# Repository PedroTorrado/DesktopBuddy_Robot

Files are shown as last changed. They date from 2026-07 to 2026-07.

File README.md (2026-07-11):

# Project Mimir

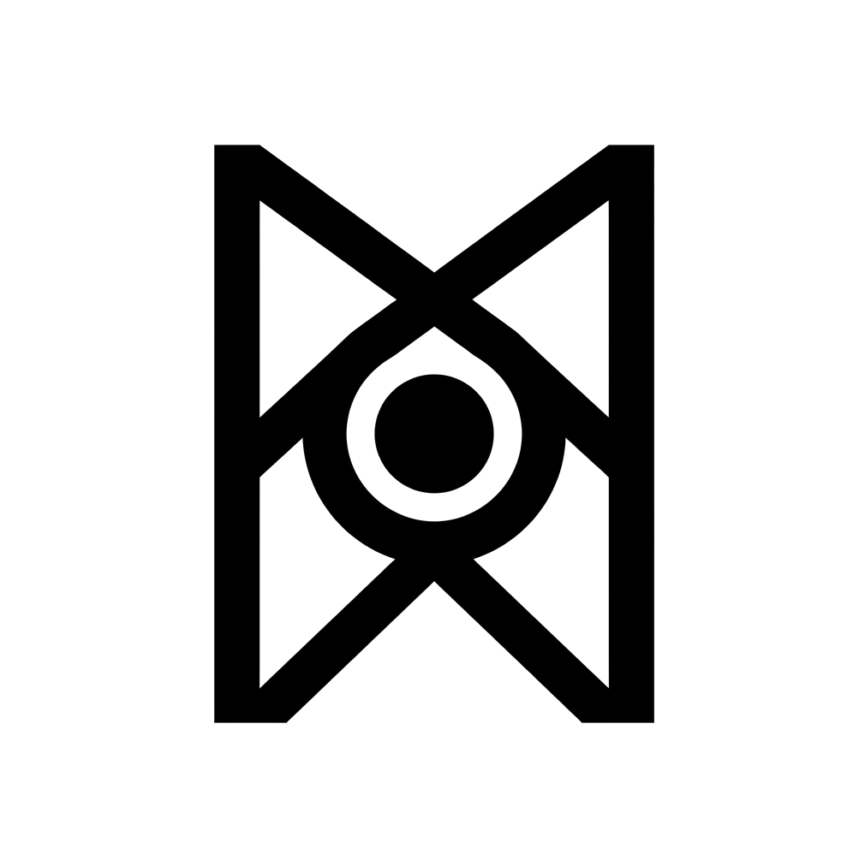
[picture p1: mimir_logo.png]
Project Mimir Logo


An autonomous, reactive, and expressive robotic companion built with an ESP32-CAM and STM32 Nucleo.

## ᛗ Runic Symbolism
The project logo features the Norse rune **Mannaz (ᛗ)** representing humanity and the mind, combined with a central camera lens. This symbolizes the camera's core objective: searching for, tracking, and identifying human faces. The name *Mimir* refers to the wise Norse sentinel head whose well guards Odin's sacrificed eye.

## Features
*   **Neural Network Face Tracking**: Uses the ESP32-CAM to detect faces and dynamically tracks them using a Proportional-Integral (PI) motor loop.
*   **SD Card Wi-Fi Loader & OLED Selector Menu**: Reads custom networks on-the-fly from `/wifi.txt` on a MicroSD card. Allows interactively scanning and joining networks via the Nucleo OLED screen and button long-press.
*   **Dynamic Telemetry Refresh Rate**: Switch between **Eco (5s)** and **Turbo (1s)** refresh modes directly from the web dashboard to control cloud costs or increase responsiveness.
*   **Startup Link Verification**: Automatic serial handshake (`PING/PONG`) on boot to visually confirm TX/RX wire integrity.
*   **Emotion Engine**: A state machine that gives the robot a personality (Happy, Searching, Dizzy, Angry) based on sensor inputs.
*   **Sensory Suite**: Monitors room air quality (SGP30) and avoids collisions with ultrasonic sonar (HC-SR04).
*   **Cloud Telemetry**: Streams data to AWS IoT Core over MQTT.

## Expressive Personalities
Project Mimir uses its SSD1306 OLED display to express its emotions dynamically based on sensor inputs:

### HAPPY (Tracking)
```text
                   ▄█▄                     ▄█▄
                 ▄██▀██▄                 ▄██▀██▄
               ▄██▀   ▀██              ▄██▀   ▀██
               █▀       ▀              █▀       ▀

                      █▄                 ▄
                      ▀██▄             ▄██
                        ▀██▄         ▄██▀
                          ▀██▄     ▄██▀
                            ▀██▄ ▄██▀
                              ▀███▀
                                ▀
```

### ANGRY (Obstacle Alert)
```text
                        ▄█              █▄
                      ▄█▀               ▀██▄
                    ▄█▀                   ▀██▄
                  ▄█▀                       ▀██▄
                ▄█▀                           ▀██▄
               ██████████              ███████████
               ██████████              ██████████
               ██████████              ██████████
               ██████████              ██████████
               ██████████              ██████████

                                   ██████████
```

### DIZZY (Jerk/Bump)
```text
               ▀▄        ▄             ▀▄        ▄
                ▀▄      █               ▀▄      █
                 ▀▄    █                 ▀▄    █
                  ▀▄  █                   ▀▄  █
                   ▀▄█                     ▀▄█
                    █▄                      █▄
                   █ ▀▄                    █ ▀▄
                  █   ▀▄                  █   ▀▄
                 █     ▀▄                █     ▀▄
                █       ▀▄              █       ▀▄
               ▀                       ▀

                              ██   ██
                           ███  ███
```

## Documentation
Please refer to the `docs/` folder for comprehensive setup instructions:
1.  **[System Architecture](docs/system_architecture.md)**: Overview of the dual-microcontroller setup and data flow.
2.  **[Wiring Guide](docs/wiring_guide.md)**: Detailed pin-to-pin wiring for all hardware components.
3.  **[AWS IoT Setup Guide](docs/aws_iot_setup_guide.md)**: Instructions on provisioning cloud certificates and policies.

## Repository Structure
*   `/ESP32_CAM`: Arduino IDE project for the ESP32-CAM vision coprocessor.
*   `/Nucleo_F411RE`: STM32CubeIDE project for the Nucleo master controller.
*   `/docs`: Architecture diagrams and hardware setup guides.

## Quick Start
1. Copy `.env.example` to `.env` and fill in your WiFi and AWS credentials.
2. Copy `ESP32_CAM/secrets.h.example` to `ESP32_CAM/secrets.h` and paste your certificates.
3. Flash the ESP32 using the Arduino IDE.
4. Build and flash the Nucleo using STM32CubeIDE.
5. Refer to `docs/wiring_guide.md` for physical hardware connections.

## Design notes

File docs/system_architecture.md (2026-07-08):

# System Architecture

DesktopBuddy utilizes a dual-microcontroller architecture to separate heavy networking/ML workloads from precise real-time hardware control.

## 1. Vision Coprocessor (ESP32-CAM)
*   **Role**: Handles all WiFi communication, AWS IoT MQTT telemetry, and local image processing.
*   **Firmware**: Arduino C++ (ESP32 core).
*   **ML Pipeline**: Runs an MTNN-based neural network to detect human faces.
*   **Output**: Transmits bounding box coordinates `FACE:ID,X,Y` over a 115200 baud UART serial connection to the Nucleo.

## 2. Master Controller (STM32 Nucleo-F411RE)
*   **Role**: Real-time operating system managing the motors, sensors, and OLED display.
*   **Firmware**: Bare-metal C generated via STM32CubeMX / HAL library.
*   **Modules**:
    *   **Proportional-Integral (PI) Controller**: Parses UART face coordinates and dynamically adjusts dual-motor PWM signals to keep the target centered.
    *   **Emotion Engine State Machine**: A `while(1)` loop that constantly evaluates sensor inputs to determine the robot's mood:
        *   `EMOTION_HAPPY` (Default/Tracking face)
        *   `EMOTION_SEARCHING` (Idle timeout > 10 seconds without face detection)
        *   `EMOTION_DIZZY` (ADXL345 accelerometer jerk detection)
        *   `EMOTION_ANGRY` (HC-SR04 ultrasonic distance < threshold)
    *   **I2C Subsystem**: Polls the SGP30 (eCO2/TVOC), ADXL345 (XYZ acceleration), and pushes bitmap frames to the SSD1306 OLED display.

## System Diagram
```mermaid
graph TD
    subgraph ESP32-CAM [Vision Coprocessor]
        CAM[Camera Module] --> ML[Face Detection Engine]
        ML -->|FACE:ID,X,Y| UART_TX0[UART0 TX - GPIO1/U0T]
        
        UART_RX0[UART0 RX - GPIO3/U0R] -->|Raw Telemetry| AWS[AWS IoT Core MQTT]
    end

    subgraph STM32 Nucleo [Master Controller]
        UART_RX1[USART1 RX - PA10/D2] --> PID[PI Tracking Loop]
        PID --> PWM[TIM3 Motor PWM]
        
        SENSORS[ADXL345 / SGP30 / HC-SR04] --> STATE[Emotion State Machine]
        STATE --> OLED[SSD1306 Display]
        
        STATE & SENSORS -->|TELEMETRY:co2,tvoc,dist,emotion| UART_TX1[USART1 TX - PB6/D10]
    end

    UART_TX0 -->|Physical Wire| UART_RX1
    UART_TX1 -->|Physical Wire| UART_RX0
```

## 3. Advanced Features

### 3.1 SD Card Wi-Fi Loader & OLED Selection Menu
*   **SD Card Parsing**: On boot, the ESP32-CAM mounts the MicroSD card in 1-bit mode, reads Wi-Fi credentials from `/sdcard/wifi.txt`, parses them, and immediately ends the SD interface to free up pin conflicts.
*   **Preferences Storage**: The ESP32-CAM saves the last successfully connected Wi-Fi credentials in non-volatile storage (NVS) using the `Preferences` library, attempting connection to it first on next boot.
*   **OLED Wi-Fi Selector**: Long-pressing the PC13 button on the Nucleo opens the Wi-Fi Selection Menu. The user can single-press to scroll through the SSIDs and long-press to select. The Nucleo sends a `SELWIFI:<index>` UART command to trigger the ESP32-CAM to connect.
*   **Status Reporting**: The ESP32-CAM sends connection updates (`WIFISTATUS:CONNECTED`, `WIFISTATUS:FAILED`, `WIFISTATUS:CONNECTING,<SSID>`) back to the Nucleo for real-time status reporting on the OLED.

### 3.2 Dynamic Telemetry Refresh Rate
*   The dashboard allows users to adjust the telemetry refresh rate (5s Eco mode or 1s Turbo mode).
*   The dashboard publishes this change to AWS IoT Core MQTT topic `esp32/face_tracker/control`.
*   The ESP32-CAM receives it via MQTT and forwards a `SETINTERVAL:<rate>` UART packet to the Nucleo.
*   The Nucleo dynamically adjusts its internal telemetry timer to update the dashboard at the requested frequency.

### 3.3 Boot Handshake Link Verification
*   Upon boot, the Nucleo enters a loop sending `PING\n` over UART to verify the serial link.
*   The ESP32-CAM immediately responds with `PONG\n`.
*   The Nucleo marks the connection as verified (`SYS RUN  C:OK`) and displays the status on the OLED screen.

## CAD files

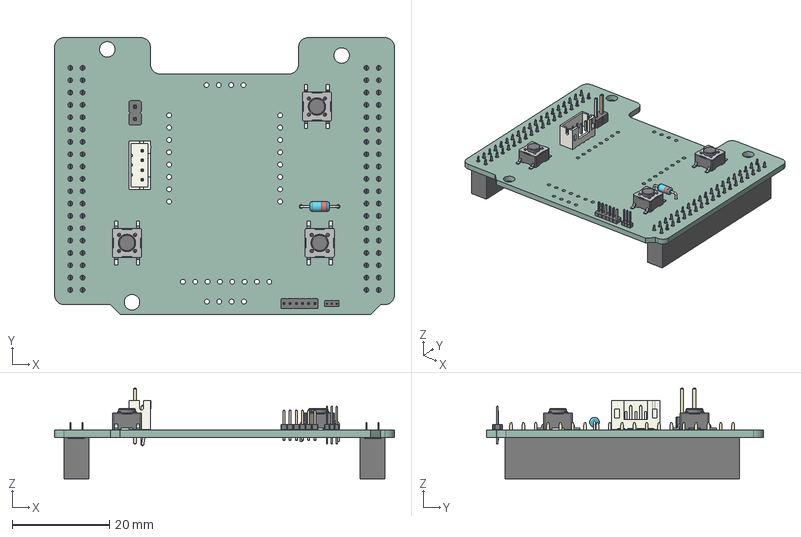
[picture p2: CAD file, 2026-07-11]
CAD/ecad/components/pcb.step
70.0 x 57.0 x 18.7 mm
SW_SPST_PTS645Sx43SMTR92 x 3
JST_B4B_PH_K
PinHeader_1x06_P127mm_Vertical
D_DO-35_SOD27_P7.62mm_Horizontal
PinHeader_1x02_P254mm_Vertical
PinHeader_1x03_P100mm_Vertical
PinSocket_2x19_P2.54mm_Vertical x 2
nucleo_shield_pcb_PCB

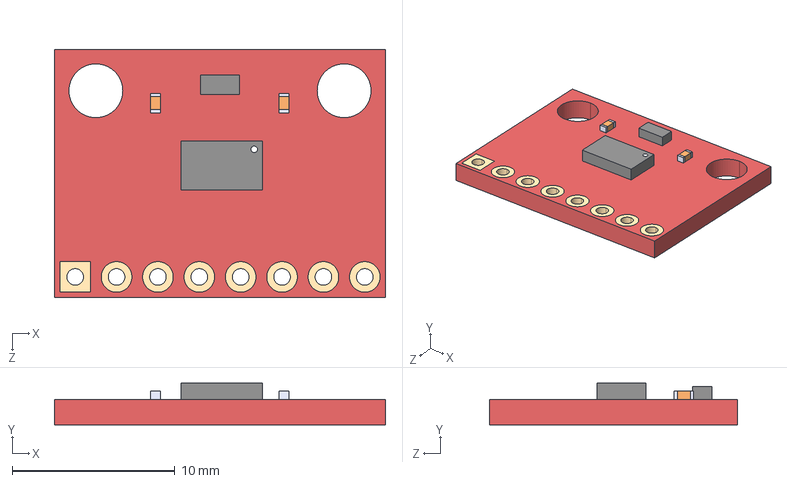
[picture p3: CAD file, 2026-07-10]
CAD/ecad/components/SEN-09836.step
20.3 x 2.57 x 15.2 mm

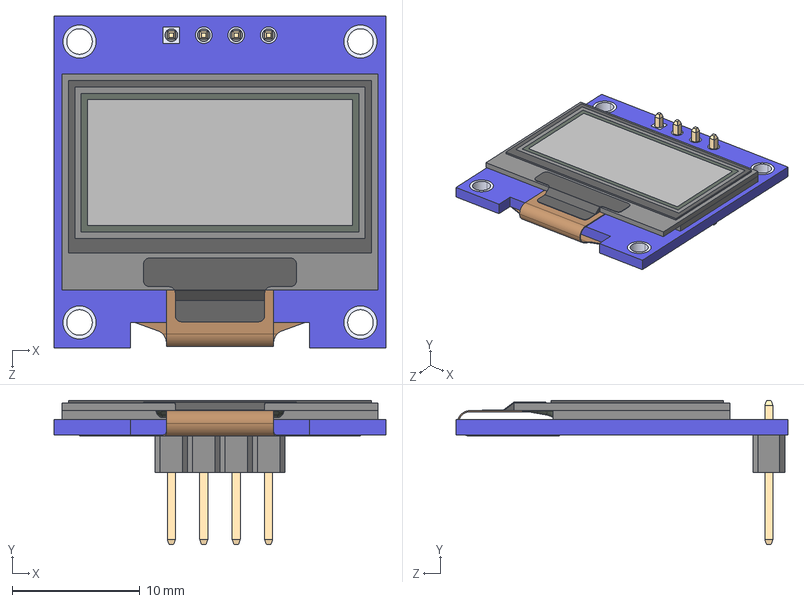
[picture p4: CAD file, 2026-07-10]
CAD/ecad/components/DM-OLED096-636.step
26.0 x 11.3 x 26.0 mm
DM-OLED096-636_Module
DM-OLED096-636_Panel

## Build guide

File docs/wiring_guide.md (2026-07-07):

# Wiring Guide

This document outlines the hardware connections required to build DesktopBuddy.

> **IMPORTANT: Common Ground**
> All components (Nucleo, ESP32, Sensors, and Motor Driver) MUST share a common Ground (GND) connection. Failure to connect grounds will result in signals not being recognized.

## 1. Microcontroller Communication (ESP32-CAM to Nucleo)
The ESP32-CAM acts as the vision coprocessor and communicates with the Nucleo master via UART.

| ESP32-CAM Pin | Nucleo F411RE Pin | Function |
| :--- | :--- | :--- |
| U0T (TX) | **PA10** (UART RX) | Serial Data to Nucleo (Arduino D2) |
| U0R (RX) | **PB6** (UART TX) | Serial Data to ESP32 (Arduino D10) |
| Pin 14 | **PC8** | Wake-up / Interrupt Signal |
| GND | GND | Common Ground |

## 2. L298N Motor Driver
We use TIM3 for hardware PWM (speed control) and GPIOB for directional control. Because of the number of peripherals, some direction pins are located on the ST Morpho headers.

**Speed Control (Arduino Headers):**
| L298N Pin | Nucleo Pin | Location | Function |
| :--- | :--- | :--- | :--- |
| ENA | **PA6** | Arduino D12 | Left Motor Speed |
| ENB | **PA7** | Arduino D11 | Right Motor Speed |

**Direction Control (Morpho Headers):**
| L298N Pin | Nucleo Pin | Location | Function |
| :--- | :--- | :--- | :--- |
| IN1 | **PB13** | Morpho CN10, Pin 31 | Left Motor Fwd |
| IN2 | **PB14** | Morpho CN10, Pin 32 | Left Motor Rev |
| IN3 | **PB15** | Morpho CN10, Pin 33 | Right Motor Fwd |
| IN4 | **PB1**  | Morpho CN7, Pin 27 | Right Motor Rev |

*Note: You must remove the ENA/ENB plastic jumpers on the L298N to use PWM speed control.*

## 3. I2C Sensor Suite
The ADXL345 (Accelerometer), SGP30 (Air Quality), and the OLED Display all share the same I2C bus. Connect them in parallel.

| Sensor Pin | Nucleo F411RE Pin |
| :--- | :--- |
| SDA | **PB9** |
| SCL | **PB8** |
| VCC | **3.3V** *(Do not use 5V!)* |
| GND | GND |

## 4. HC-SR04 Ultrasonic Distance Sensor
Provides collision avoidance for the front bumper. The Nucleo F411RE pins used are 5V-tolerant (FT).

| HC-SR04 Pin | Nucleo F411RE Pin |
| :--- | :--- |
| TRIG | **PA8** (Arduino D7) |
| ECHO | **PC7** (Arduino D9) |
| VCC | **5V** |
| GND | GND |

## Power Considerations
*   **Motors:** Use a dedicated power supply (e.g., 5V Power Bank or battery pack) connected to the 12V and GND terminals on the L298N. Do not power the motors from the Nucleo.
*   **ESP32:** Requires up to 400mA during WiFi transmission. Power it from a stable 5V source.

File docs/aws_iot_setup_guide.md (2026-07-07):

# AWS IoT Core Setup Guide

To enable cloud telemetry for DesktopBuddy, you need to configure an AWS IoT "Thing" and retrieve the necessary certificates.

## 1. Create a Policy
1. Go to **AWS IoT Core** -> **Security** -> **Policies**.
2. Click **Create**.
3. Name it `DesktopBuddyPolicy`.
4. In the Policy Document, use the following broad policy for testing (restrict this in production!):
   * Action: `iot:*`
   * Resource ARN: `*`
   * Effect: `Allow`
5. Click **Create**.

## 2. Create the Thing & Certificates
1. Go to **Manage** -> **Things** and click **Create things**.
2. Select **Create single thing**, name it `ESP32-CAM-Tracker`.
3. Select **Auto-generate a new certificate**.
4. Attach the `DesktopBuddyPolicy` you created earlier.
5. **CRITICAL STEP**: Download all generated certificates immediately:
   * Device Certificate (`xxxx-certificate.pem.crt`)
   * Private Key (`xxxx-private.pem.key`)
   * Amazon Root CA 1 (`AmazonRootCA1.pem`)

## 3. Configure the Code
Open your `secrets.h` file (create it from `secrets.h.example`) and insert the contents of your downloaded certificates. 

*Note: You must include the `-----BEGIN CERTIFICATE-----` and `-----END CERTIFICATE-----` headers exactly as they appear in the files.*

## 4. Find Your Endpoint
1. In the AWS IoT Core console, click **Settings** (bottom left).
2. Copy your **Endpoint** (it looks like `a2xxxxxxxxxxxx-ats.iot.region.amazonaws.com`).
3. Paste this into the `AWS_IOT_ENDPOINT` variable in `secrets.h`.

Once the ESP32 is flashed, you can view the live telemetry by going to **MQTT test client** in AWS IoT and subscribing to the topic: `esp32/face_tracker/data`.

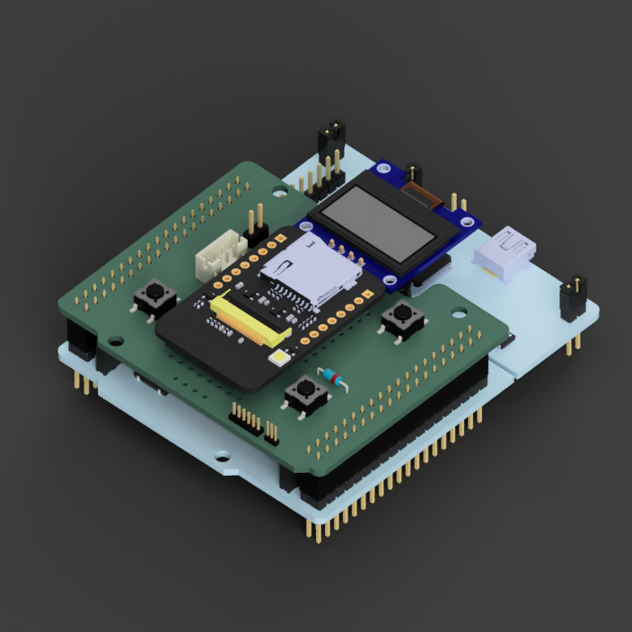
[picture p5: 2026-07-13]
CAD/render/Mounting_Assembly_Concept.png

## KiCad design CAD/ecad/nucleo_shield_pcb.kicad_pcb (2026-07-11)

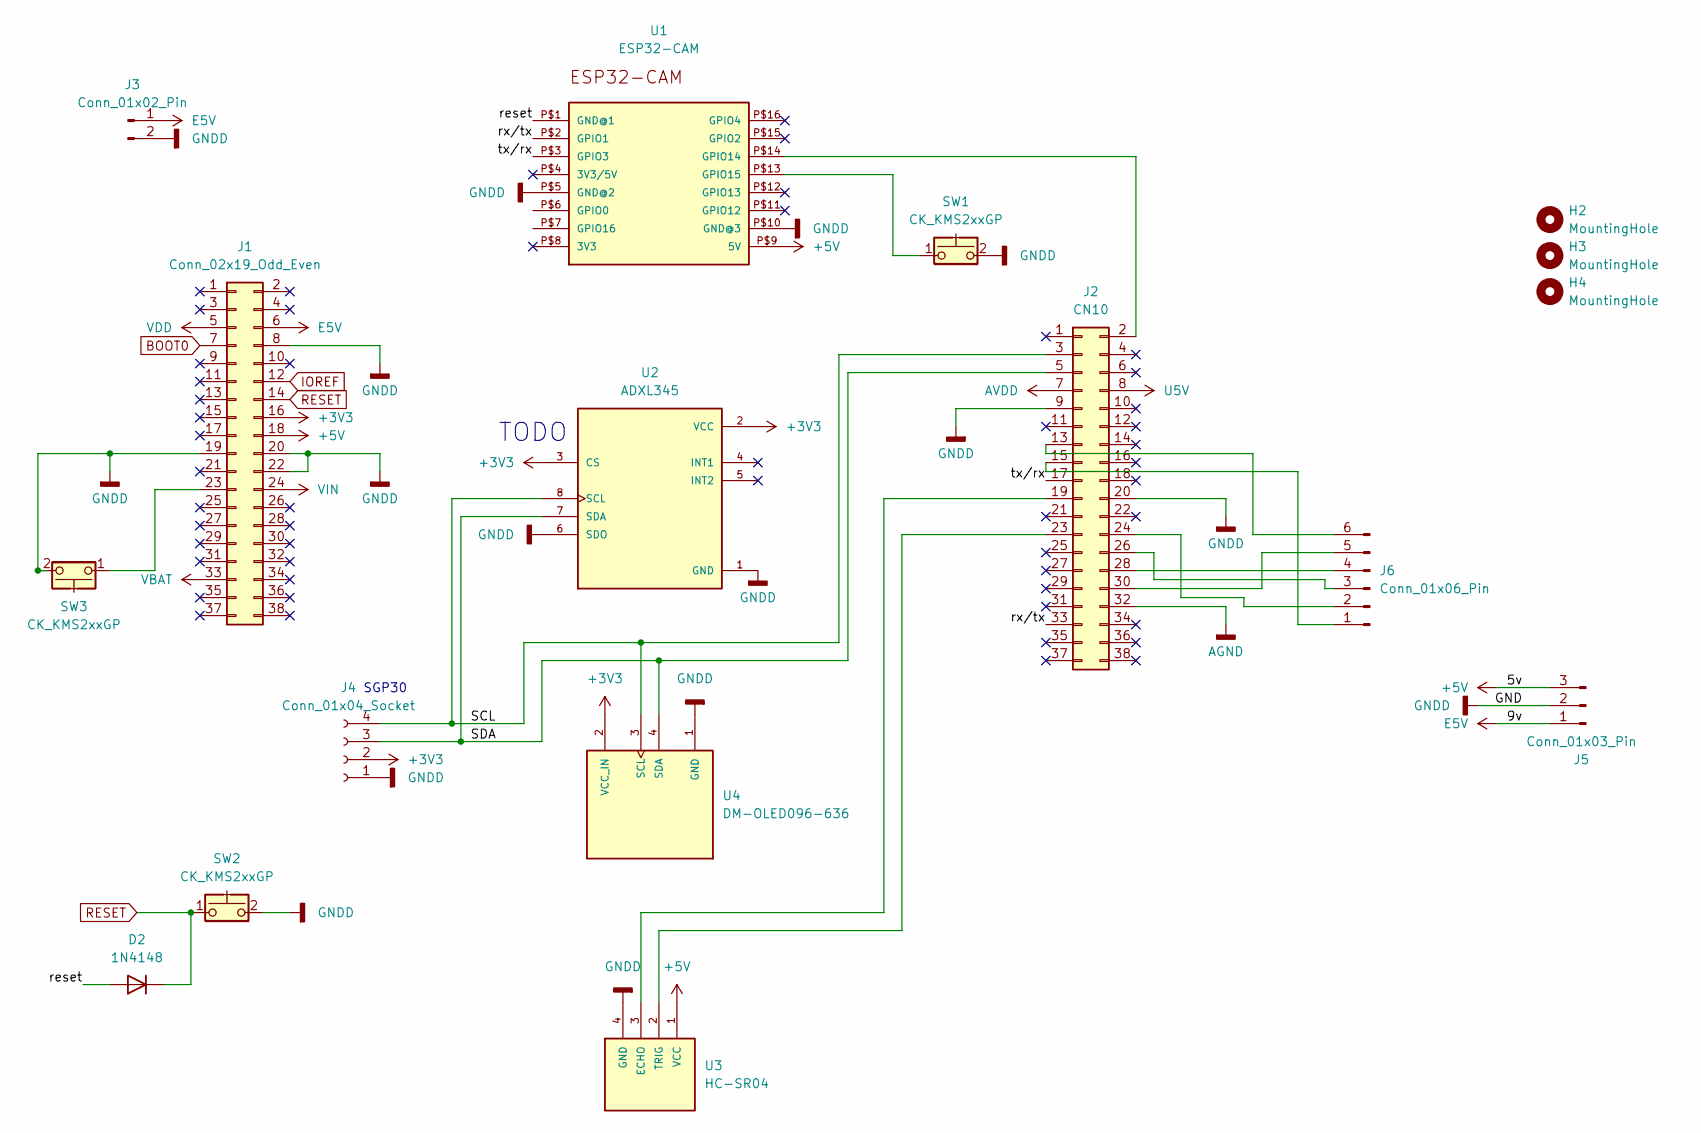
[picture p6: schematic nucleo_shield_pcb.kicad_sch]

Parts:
D2: 1N4148; D_DO-35_SOD27_P7.62mm_Horizontal
H2, H3, H4: MountingHole; MountingHole_3.2mm_M3_ISO14580
J1: Conn_02x19_Odd_Even; PinSocket_2x19_P2.54mm_Vertical
J2: CN10; PinSocket_2x19_P2.54mm_Vertical
J3: Conn_01x02_Pin; PinHeader_1x02_P2.54mm_Vertical
J4: Conn_01x04_Socket; JST_PH_B4B-PH-K_1x04_P2.00mm_Vertical
J5: Conn_01x03_Pin; PinHeader_1x03_P1.00mm_Vertical
J6: Conn_01x06_Pin; PinHeader_1x06_P1.27mm_Vertical
SW1, SW2, SW3: CK_KMS2xxGP; SW_SPST_PTS645Sx43SMTR92
U1: ESP32-CAM
U2: ADXL345; MODULE_SEN-09836; PARTREV v14
U3: HC-SR04; XCVR_HC-SR04
U4: DM-OLED096-636; MODULE_DM-OLED096-636; PARTREV 2018-09-10

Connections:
+3V3: J1.16, J4.2, U2.2 (VCC), U2.3 (CS), U4.2 (VCC_IN)
+5V: J1.18, J5.3, U1.P$9 (5V), U3.1 (VCC)
/SCL: J2.3, J4.4, U2.8 (SCL), U4.3 (SCL)
/SDA: J2.5, J4.3, U2.7 (SDA), U4.4 (SDA)
/reset: D2.2 (A), U1.P$1 (GND@1)
/rx/tx: J2.33, U1.P$2 (GPIO1)
/tx/rx: J2.17, U1.P$3 (GPIO3)
AGND: J2.32
AVDD: J2.7
BOOT0: J1.7
E5V: J1.6, J3.1, J5.1
GNDD: J1.8, J1.19, J1.20, J1.22, J2.9, J2.20, J3.2, J4.1, J5.2, SW1.2, SW2.2, SW3.2, U1.P$5 (GND@2), U1.P$10 (GND@3), U2.1 (GND), U2.6 (SDO), U3.4 (GND), U4.1 (GND)
IOREF: J1.12
unnamed: J1.23, SW3.1
unnamed: J2.2, U1.P$14 (GPIO14)
unnamed: J2.13, J6.6
unnamed: J2.15, J6.1
unnamed: J2.19, U3.3 (ECHO)
unnamed: J2.23, U3.2 (TRIG)
unnamed: J2.24, J6.2
unnamed: J2.26, J6.3
unnamed: J2.28, J6.4
unnamed: J2.30, J6.5
unnamed: SW1.1, U1.P$13 (GPIO15)
RESET: D2.1 (K), J1.14, SW2.1
U5V: J2.8
VBAT: J1.33
VDD: J1.5
VIN: J1.24

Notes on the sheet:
TODO
SGP30

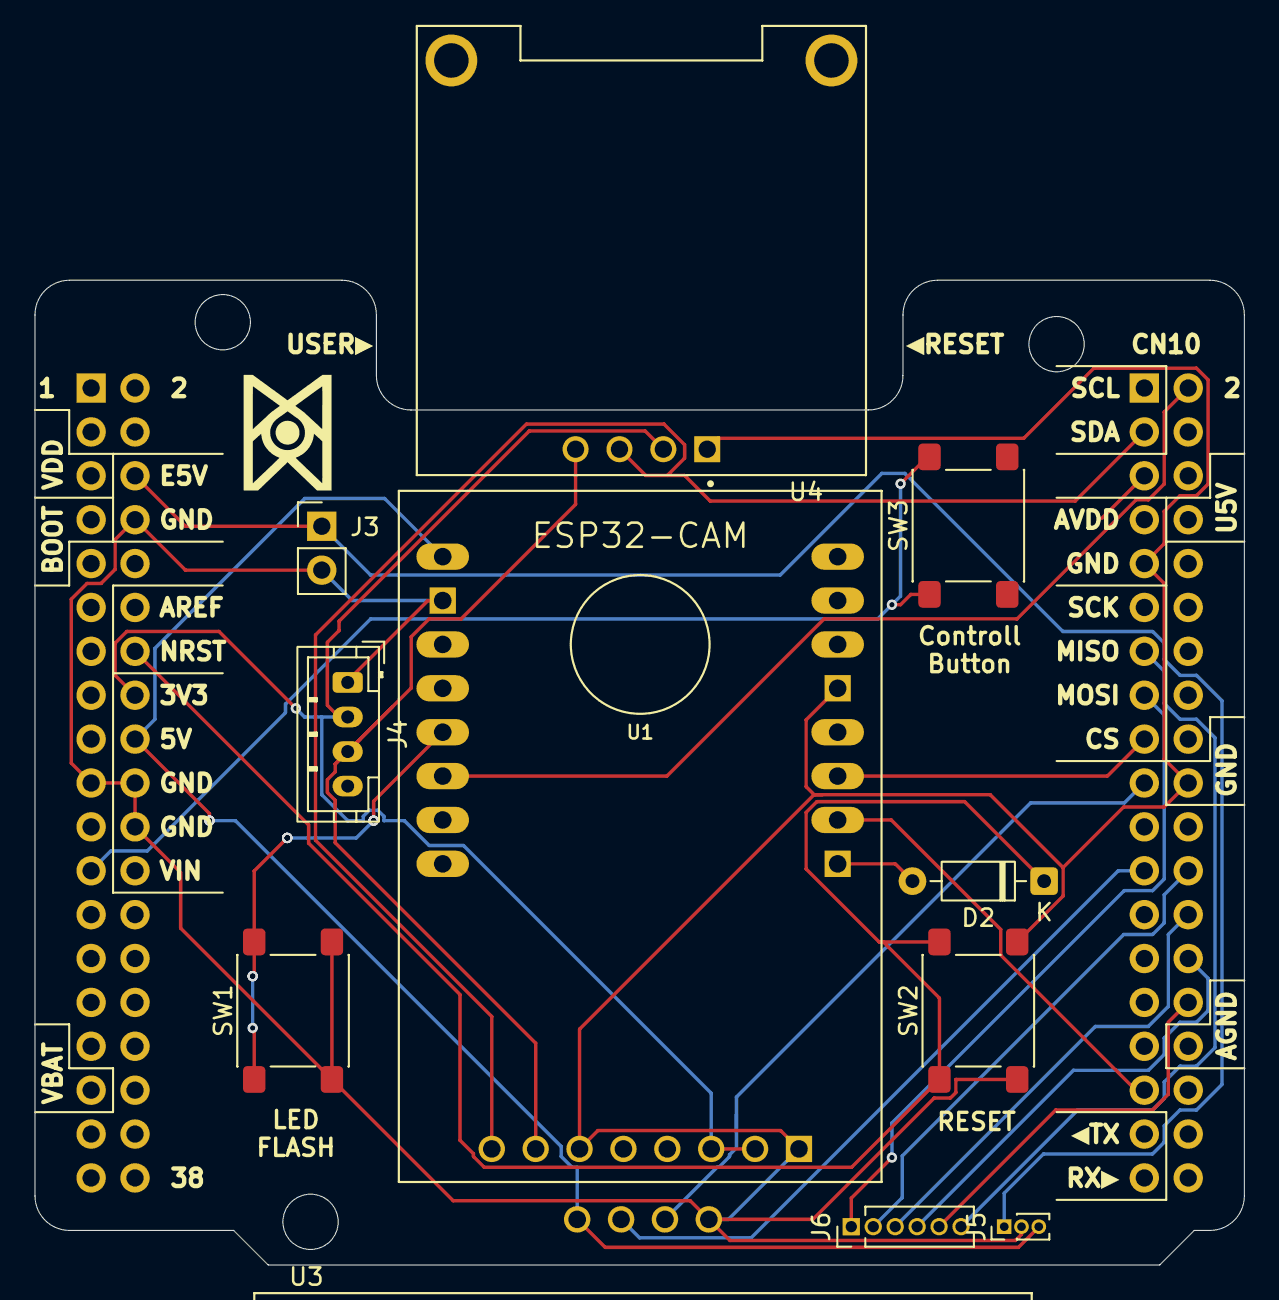
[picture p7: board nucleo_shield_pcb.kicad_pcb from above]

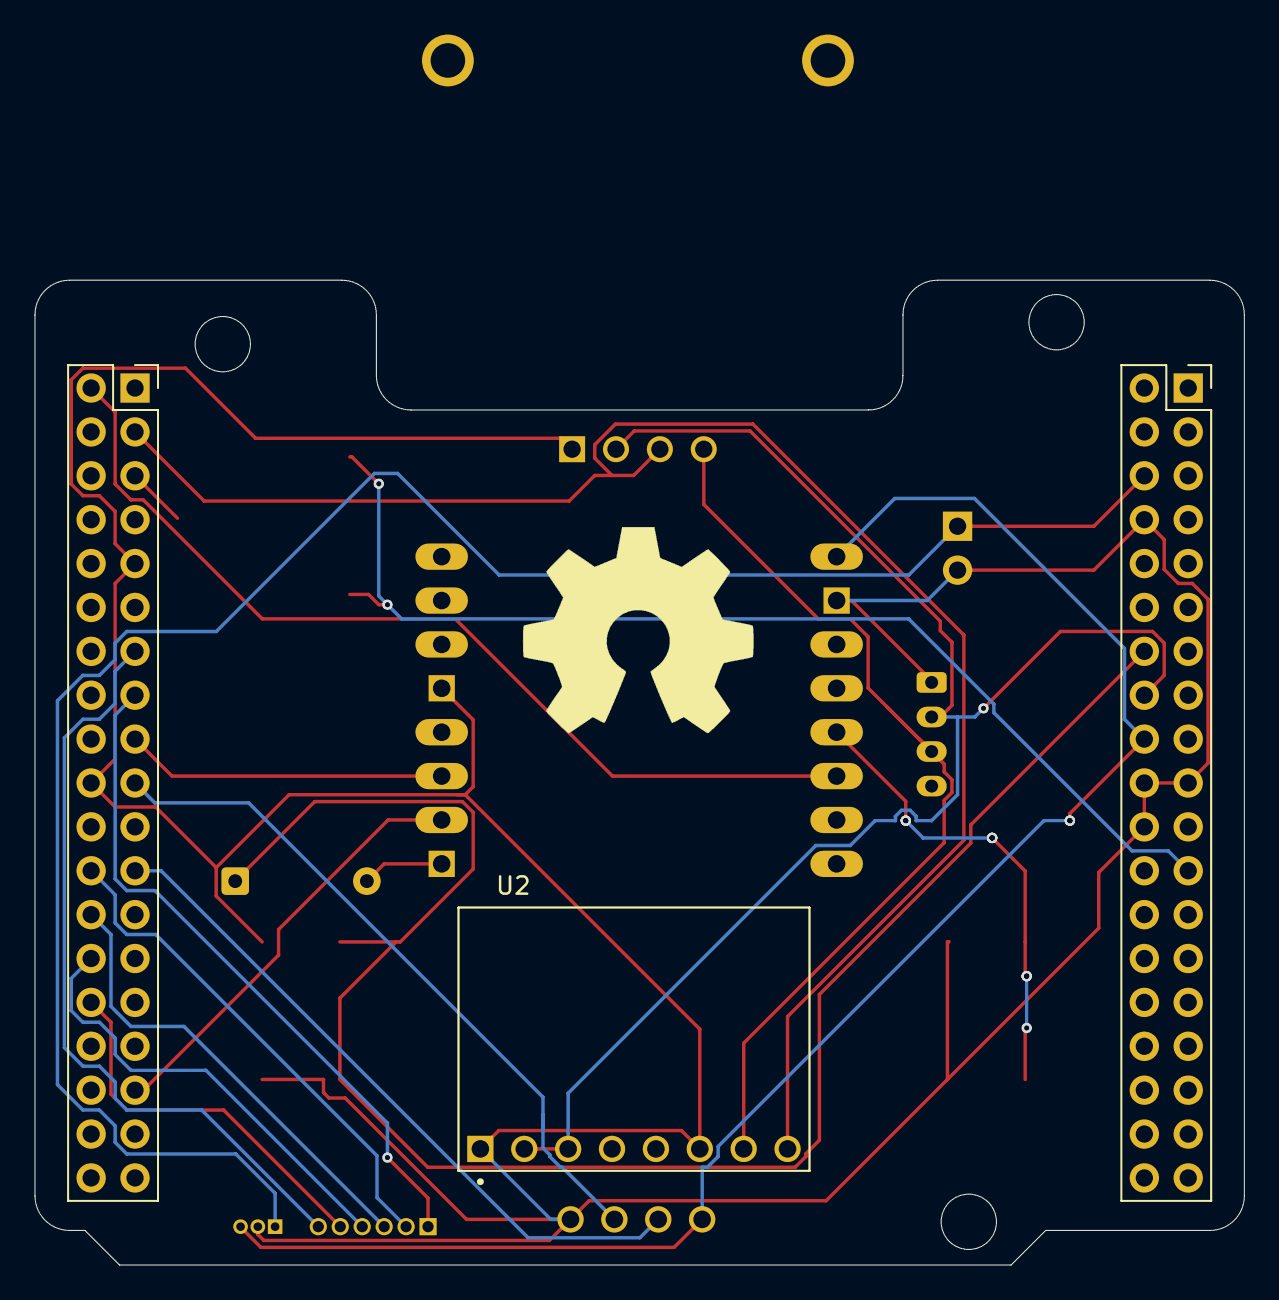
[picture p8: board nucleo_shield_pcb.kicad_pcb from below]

Board: 2 copper layers, 70.0 x 57.0 mm, 17 parts (3 on the bottom side), 21 nets.

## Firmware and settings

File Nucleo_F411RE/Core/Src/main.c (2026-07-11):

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
/* Includes ------------------------------------------------------------------*/
#include "main.h"

/* USER CODE BEGIN Includes */
#include <stdio.h>
#include <string.h>
/* USER CODE END Includes */

I2C_HandleTypeDef hi2c1;

TIM_HandleTypeDef htim3;

UART_HandleTypeDef huart1;
UART_HandleTypeDef huart2;

/* USER CODE BEGIN PV */
volatile uint8_t uart1_rx_byte;
volatile char esp32_rx_buffer[256];
volatile uint8_t esp32_rx_index = 0;
volatile uint32_t uart_rx_count = 0;
volatile char cmd_rx_buffer[256];
volatile uint8_t cmd_rx_ready = 0;

volatile int target_face_x = 0;
volatile int target_face_y = 0;
volatile int face_detected = 0;
volatile uint32_t last_face_time = 0;

// Globals for Webpage Manual Control
volatile uint32_t last_manual_command_time = 0;
volatile int manual_left_speed = 0;
volatile int manual_right_speed = 0;

// Globals for Motor Acceleration Ramping (Soft Start)
volatile int target_left_speed = 0;
volatile int target_right_speed = 0;
volatile int current_left_speed = 0;
volatile int current_right_speed = 0;

// Globals for Webpage & Screen Menu Button options
volatile uint32_t button_pressed_time = 0;
volatile uint8_t button_held = 0;
volatile uint8_t face_detect_pin_state = 1; // Default ON (sets GPIOC Pin 8 to HIGH)

uint16_t sgp30_co2 = 400;
uint16_t sgp30_tvoc = 0;
/* USER CODE END PV */

void SystemClock_Config(void);
static void MX_GPIO_Init(void);
static void MX_USART2_UART_Init(void);
static void MX_I2C1_Init(void);
static void MX_TIM3_Init(void);
static void MX_USART1_UART_Init(void);
/* USER CODE BEGIN PFP */
void set_motors(int speed_left, int speed_right);
void apply_motors(int speed_left, int speed_right);

/* USER CODE END PFP */

/* USER CODE BEGIN 0 */
typedef enum {
    EMOTION_HAPPY,
    EMOTION_ANGRY,
    EMOTION_SEARCHING,
    EMOTION_DIZZY
} RobotEmotion;

RobotEmotion current_emotion = EMOTION_HAPPY;
uint32_t last_bop_time = 0;

void DWT_Delay_us(uint32_t us) {
    // Software delay calibrated for 16MHz HSI clock
    // us * 3 is roughly 1 microsecond of delay including loop overhead
    volatile uint32_t delay = us * 3;
    while (delay--);
}

int HCSR04_Read(void) {
    HAL_GPIO_WritePin(GPIOA, GPIO_PIN_8, GPIO_PIN_RESET);
    DWT_Delay_us(2);
    HAL_GPIO_WritePin(GPIOA, GPIO_PIN_8, GPIO_PIN_SET);
    DWT_Delay_us(10);
    HAL_GPIO_WritePin(GPIOA, GPIO_PIN_8, GPIO_PIN_RESET);
    
    // Software timeout loop instead of DWT timer
    uint32_t timeout = 0;
    while (HAL_GPIO_ReadPin(GPIOC, GPIO_PIN_7) == GPIO_PIN_RESET) {
        if (timeout++ > 50000) return -1;
    }
    
    uint32_t pulse_width = 0;
    while (HAL_GPIO_ReadPin(GPIOC, GPIO_PIN_7) == GPIO_PIN_SET) {
        pulse_width++;
        // Very short delay for calibration
        volatile uint32_t delay = 2;
        while(delay--);
        if (pulse_width > 60000) return -1;
    }
    
    // Calibrated divisor for software loop
    return pulse_width / 25;
}

void SGP30_Init(void) {
    uint8_t cmd[2] = {0x20, 0x03};
    HAL_I2C_Master_Transmit(&hi2c1, 0x58 << 1, cmd, 2, 100);
}

void SGP30_Measure(uint16_t *co2, uint16_t *tvoc) {
    uint8_t cmd[2] = {0x20, 0x08};
    HAL_I2C_Master_Transmit(&hi2c1, 0x58 << 1, cmd, 2, 100);
    HAL_Delay(12);
    uint8_t data[6];
    if (HAL_I2C_Master_Receive(&hi2c1, 0x58 << 1, data, 6, 100) == HAL_OK) {
        *co2 = (data[0] << 8) | data[1];
        *tvoc = (data[3] << 8) | data[4];
    }
}

void set_motors(int speed_left, int speed_right) {
    target_left_speed = speed_left;
    target_right_speed = speed_right;
}

void apply_motors(int speed_left, int speed_right) {
    if (speed_left > 0) {
        HAL_GPIO_WritePin(GPIOB, GPIO_PIN_13, GPIO_PIN_SET);
        HAL_GPIO_WritePin(GPIOB, GPIO_PIN_14, GPIO_PIN_RESET);
    } else if (speed_left < 0) {
        HAL_GPIO_WritePin(GPIOB, GPIO_PIN_13, GPIO_PIN_RESET);
        HAL_GPIO_WritePin(GPIOB, GPIO_PIN_14, GPIO_PIN_SET);
        speed_left = -speed_left;
    } else {
        HAL_GPIO_WritePin(GPIOB, GPIO_PIN_13, GPIO_PIN_RESET);
        HAL_GPIO_WritePin(GPIOB, GPIO_PIN_14, GPIO_PIN_RESET);
    }
    
    if (speed_right > 0) {
        HAL_GPIO_WritePin(GPIOB, GPIO_PIN_15, GPIO_PIN_SET);
        HAL_GPIO_WritePin(GPIOB, GPIO_PIN_1, GPIO_PIN_RESET);
    } else if (speed_right < 0) {
        HAL_GPIO_WritePin(GPIOB, GPIO_PIN_15, GPIO_PIN_RESET);
        HAL_GPIO_WritePin(GPIOB, GPIO_PIN_1, GPIO_PIN_SET);
        speed_right = -speed_right;
    } else {
        HAL_GPIO_WritePin(GPIOB, GPIO_PIN_15, GPIO_PIN_RESET);
        HAL_GPIO_WritePin(GPIOB, GPIO_PIN_1, GPIO_PIN_RESET);
    }

    if (speed_left > 999) speed_left = 999;
    if (speed_right > 999) speed_right = 999;

    // Scale 0-1000 speed range to 0-65535 PWM period of TIM3
    uint32_t compare_left = (speed_left * 65535) / 1000;
    uint32_t compare_right = (speed_right * 65535) / 1000;

    __HAL_TIM_SET_COMPARE(&htim3, TIM_CHANNEL_1, compare_left);
    __HAL_TIM_SET_COMPARE(&htim3, TIM_CHANNEL_2, compare_right);
}

void track_face() {
    if (face_detected) {
        int error = target_face_x - 160;
        int base_speed = 300; 
        int turn_speed = error * 3; 
        int left = base_speed + turn_speed;
        int right = base_speed - turn_speed;
        set_motors(left, right);
    } else {
        set_motors(0, 0);
    }
}

#define OLED_ADDR        (0x3C << 1)

void OLED_WriteCommand(uint8_t cmd) {
    uint8_t buffer[2];
    buffer[0] = 0x00;
    buffer[1] = cmd;
    HAL_I2C_Master_Transmit(&hi2c1, OLED_ADDR, buffer, 2, 10);
}

void OLED_Init(void) {
    HAL_Delay(200);
    OLED_WriteCommand(0xAE);
    OLED_WriteCommand(0xD5); OLED_WriteCommand(0x80);
    OLED_WriteCommand(0xA8); OLED_WriteCommand(0x3F);
    OLED_WriteCommand(0xD3); OLED_WriteCommand(0x00);
    OLED_WriteCommand(0x40);
    OLED_WriteCommand(0x8D); OLED_WriteCommand(0x14);
    OLED_WriteCommand(0x20); OLED_WriteCommand(0x00);
    OLED_WriteCommand(0xA1);
    OLED_WriteCommand(0xC8);
    OLED_WriteCommand(0xDA); OLED_WriteCommand(0x12);
    OLED_WriteCommand(0x81); OLED_WriteCommand(0x7F);
    OLED_WriteCommand(0xD9); OLED_WriteCommand(0x22);
    OLED_WriteCommand(0xDB); OLED_WriteCommand(0x20);
    OLED_WriteCommand(0xA4); OLED_WriteCommand(0xA6);
    OLED_WriteCommand(0xAF);
    HAL_Delay(10);
}

void OLED_Clear(void) {
    OLED_WriteCommand(0x21); OLED_WriteCommand(0); OLED_WriteCommand(127);
    OLED_WriteCommand(0x22); OLED_WriteCommand(0); OLED_WriteCommand(7);
    static uint8_t clear_buf[129];
    clear_buf[0] = 0x40;
    for(int i = 1; i <= 128; i++) clear_buf[i] = 0x00;
    for(int page = 0; page < 8; page++) {
        HAL_I2C_Master_Transmit(&hi2c1, OLED_ADDR, clear_buf, 129, 50);
    }
}

const uint8_t BasicFont[41][5] = {
    {0x3E, 0x51, 0x49, 0x45, 0x3E}, // 0
    {0x00, 0x42, 0x7F, 0x40, 0x00}, // 1
    {0x42, 0x61, 0x51, 0x49, 0x46}, // 2
    {0x21, 0x41, 0x45, 0x4B, 0x31}, // 3
    {0x18, 0x14, 0x12, 0x7F, 0x10}, // 4
    {0x27, 0x45, 0x45, 0x45, 0x39}, // 5
    {0x3C, 0x4A, 0x49, 0x49, 0x30}, // 6
    {0x01, 0x71, 0x09, 0x05, 0x03}, // 7
    {0x36, 0x49, 0x49, 0x49, 0x36}, // 8
    {0x06, 0x49, 0x49, 0x29, 0x1E}, // 9
    {0x7E, 0x11, 0x11, 0x11, 0x7E}, // A
    {0x7F, 0x49, 0x49, 0x49, 0x36}, // B
    {0x3E, 0x41, 0x41, 0x41, 0x22}, // C
    {0x7F, 0x41, 0x41, 0x22, 0x1C}, // D
    {0x7F, 0x49, 0x49, 0x49, 0x41}, // E
    {0x7F, 0x09, 0x09, 0x09, 0x01}, // F
    {0x3E, 0x41, 0x49, 0x49, 0x7A}, // G
    {0x7F, 0x08, 0x08, 0x08, 0x7F}, // H
    {0x00, 0x41, 0x7F, 0x41, 0x00}, // I
    {0x20, 0x40, 0x41, 0x3F, 0x01}, // J
    {0x7F, 0x08, 0x14, 0x22, 0x41}, // K
    {0x7F, 0x40, 0x40, 0x40, 0x40}, // L
    {0x7F, 0x02, 0x0C, 0x02, 0x7F}, // M
    {0x7F, 0x04, 0x08, 0x10, 0x7F}, // N
    {0x3E, 0x41, 0x41, 0x41, 0x3E}, // O
    {0x7F, 0x09, 0x09, 0x09, 0x06}, // P
    {0x3E, 0x41, 0x51, 0x21, 0x5E}, // Q
    {0x7F, 0x09, 0x19, 0x29, 0x46}, // R
    {0x46, 0x49, 0x49, 0x49, 0x31}, // S
    {0x01, 0x01, 0x7F, 0x01, 0x01}, // T
    {0x3F, 0x40, 0x40, 0x40, 0x3F}, // U
    {0x00, 0x20, 0x40, 0x20, 0x00}, // V
    {0x3F, 0x40, 0x38, 0x40, 0x3F}, // W
    {0x63, 0x14, 0x08, 0x14, 0x63}, // X
    {0x07, 0x08, 0x70, 0x08, 0x07}, // Y
    {0x61, 0x51, 0x49, 0x45, 0x43}, // Z
    {0x00, 0x00, 0x00, 0x00, 0x00}, // [Space]
    {0x00, 0x24, 0x24, 0x24, 0x00}, // :
    {0x08, 0x08, 0x08, 0x08, 0x08}, // -
    {0x41, 0x22, 0x14, 0x08, 0x00}, // >
    {0x08, 0x14, 0x22, 0x41, 0x00}  // <
};

void OLED_PrintText(uint8_t page, uint8_t col, char* str) {
    OLED_WriteCommand(0x21); OLED_WriteCommand(col); OLED_WriteCommand(127);
    OLED_WriteCommand(0x22); OLED_WriteCommand(page); OLED_WriteCommand(7);
    static uint8_t tx_buf[6];
    tx_buf[0] = 0x40;
    while(*str) {
        uint8_t idx = 36;
        char c = *str;
        if (c >= '0' && c <= '9') idx = c - '0';
        else if (c >= 'A' && c <= 'Z') idx = (c - 'A') + 10;
        else if (c >= 'a' && c <= 'z') idx = (c - 'a') + 10;
        else if (c == ':') idx = 37;
        else if (c == '-') idx = 38;
        else if (c == '>') idx = 39;
        else if (c == '<') idx = 40;
        for(int i = 0; i < 5; i++) tx_buf[i + 1] = BasicFont[idx][i];
        HAL_I2C_Master_Transmit(&hi2c1, OLED_ADDR, tx_buf, 6, 10);
        str++;
    }
}

void OLED_DrawBitmap(const uint8_t* bitmap) {
    OLED_WriteCommand(0x21); OLED_WriteCommand(0); OLED_WriteCommand(127);
    OLED_WriteCommand(0x22); OLED_WriteCommand(0); OLED_WriteCommand(7);
    static uint8_t data_buffer[1025];
    data_buffer[0] = 0x40;
    for (int i = 0; i < 1024; i++) {
        data_buffer[i + 1] = bitmap[i];
    }
    HAL_I2C_Master_Transmit(&hi2c1, OLED_ADDR, data_buffer, 1025, 200);
}
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
int main(void)
{
  /* USER CODE BEGIN 1 */
    int pin_state = 1;
  /* USER CODE END 1 */

  /* MCU Configuration--------------------------------------------------------*/

  /* Reset of all peripherals, Initializes the Flash interface and the Systick. */
  HAL_Init();

  /* Configure the system clock */
  SystemClock_Config();

  /* Initialize all configured peripherals */
  MX_GPIO_Init();
  MX_USART2_UART_Init();
  MX_I2C1_Init();
  MX_TIM3_Init();
  MX_USART1_UART_Init();
  /* USER CODE BEGIN 2 */
    OLED_Init();
    OLED_Clear();
    
    // Start ESP32 UART Listener
    HAL_UART_Receive_IT(&huart1, &uart1_rx_byte, 1);

    // Start Motor PWM
    HAL_TIM_PWM_Start(&htim3, TIM_CHANNEL_1);
    HAL_TIM_PWM_Start(&htim3, TIM_CHANNEL_2);
    
    // Startup motor wiggle test to confirm operation
    set_motors(350, -350);
    HAL_Delay(150);
    set_motors(-350, 350);
    HAL_Delay(150);
    set_motors(0, 0);
    
    // Enable DWT Cycle Counter for HC-SR04 microsecond delays
    CoreDebug->DEMCR |= CoreDebug_DEMCR_TRCENA_Msk;
    DWT->CYCCNT = 0;
    DWT->CTRL |= DWT_CTRL_CYCCNTENA_Msk;

    // Wake up the ESP32 by pulling PC8 (connected to ESP32 Pin 14) HIGH
    HAL_GPIO_WritePin(GPIOC, GPIO_PIN_8, GPIO_PIN_SET);
    
    // Initialize SGP30
    SGP30_Init();

    uint8_t dev_id = 0;
    HAL_I2C_Mem_Read(&hi2c1, 0xA6, 0x00, I2C_MEMADD_SIZE_8BIT, &dev_id, 1, 100);

    uint8_t raw_data[6];
    int16_t x_accel, y_accel, z_accel;
    int16_t x_offset = 0, y_offset = 0, z_offset = 0;

    #define FILTER_DEPTH  8
    int16_t x_history[FILTER_DEPTH] = {0};
    int16_t y_history[FILTER_DEPTH] = {0};
    int16_t z_history[FILTER_DEPTH] = {0};
    uint8_t filter_idx = 0;

    if (dev_id == 0xE5) {
        printf("ADXL345 Logged On Successfully!\r\n");
        uint8_t power_ctl_data = 0x08;
        HAL_I2C_Mem_Write(&hi2c1, 0xA6, 0x2D, I2C_MEMADD_SIZE_8BIT, &power_ctl_data, 1, 100);
        HAL_Delay(100);

        HAL_I2C_Mem_Read(&hi2c1, 0xA6, 0x32, I2C_MEMADD_SIZE_8BIT, raw_data, 6, 100);
        x_offset = (int16_t)((raw_data[1] << 8) | raw_data[0]);
        y_offset = (int16_t)((raw_data[3] << 8) | raw_data[2]);
        z_offset = (int16_t)((raw_data[5] << 8) | raw_data[4]);

        printf("Calibrated! Offsets locked -> X:%d Y:%d Z:%d\r\n", x_offset, y_offset, z_offset);
        OLED_PrintText(0, 0, "CALIBRATED: OK ");
        HAL_Delay(1000);
        OLED_Clear();
    } else {
        printf("ADXL345 Handshake failed. Read ID: 0x%02X\r\n", dev_id);
        OLED_PrintText(0, 0, "SENSOR ERROR!");
    }
  /* USER CODE END 2 */

  /* Infinite loop */
  /* USER CODE BEGIN WHILE */
    static uint32_t last_toggle_time = 0;
        static uint32_t last_sgp_poll_time = 0;
        static uint32_t last_telemetry_send_time = 0;
        static uint16_t peak_co2 = 400;
        static uint16_t peak_tvoc = 0;
        static uint8_t display_mode = 1;      // 0 = Telemetry, 1 = Dog Canvas
        static uint8_t last_pin_state = 1;
        static uint8_t dynamic_refresh_needed = 1; // Tracks if static screens need a redraw pass
        static RobotEmotion last_rendered_emotion = EMOTION_HAPPY;
        static char wifi_status[32] = "IDLE";

        while (1)
        {
             uint32_t current_time = HAL_GetTick();

             // --- MOTOR SPEED RAMPING (Soft Start to prevent current surge / brownouts) ---
             static uint32_t last_ramp_time = 0;
             if (current_time - last_ramp_time >= 5) {
                 last_ramp_time = current_time;
                 
                 // Ramp Left Speed
                 if (current_left_speed < target_left_speed) {
                     current_left_speed += 15;
                     if (current_left_speed > target_left_speed) current_left_speed = target_left_speed;
                 } else if (current_left_speed > target_left_speed) {
                     current_left_speed -= 15;
                     if (current_left_speed < target_left_speed) current_left_speed = target_left_speed;
                 }
                 
                 // Ramp Right Speed
                 if (current_right_speed < target_right_speed) {
                     current_right_speed += 15;
                     if (current_right_speed > target_right_speed) current_right_speed = target_right_speed;
                 } else if (current_right_speed > target_right_speed) {
                     current_right_speed -= 15;
                     if (current_right_speed < target_right_speed) current_right_speed = target_right_speed;
                 }
                 
                 // Apply current ramped speeds physically
                 apply_motors(current_left_speed, current_right_speed);
             }
             
             // --- PARSE INCOMING COMMANDS FROM ESP32 ---
             if (cmd_rx_ready == 1) {
                 cmd_rx_ready = 0;
                 char local_cmd_buf[256];
                 __HAL_UART_DISABLE_IT(&huart1, UART_IT_RXNE);
                 strncpy(local_cmd_buf, (char*)cmd_rx_buffer, sizeof(local_cmd_buf) - 1);
                 local_cmd_buf[sizeof(local_cmd_buf) - 1] = '\0';
                 __HAL_UART_ENABLE_IT(&huart1, UART_IT_RXNE);
                 
                 // Strip trailing \r or \n
                 int cmd_len = strlen(local_cmd_buf);
                 while (cmd_len > 0 && (local_cmd_buf[cmd_len - 1] == '\r' || local_cmd_buf[cmd_len - 1] == '\n')) {
                     local_cmd_buf[cmd_len - 1] = '\0';
                     cmd_len--;
                 }
                 
                 if (strncmp(local_cmd_buf, "WIFISTATUS:", 11) == 0) {
                     char* status_ptr = local_cmd_buf + 11;
                     if (strncmp(status_ptr, "CONNECTING", 10) == 0) {
                         char* comma_ptr = strchr(status_ptr, ',');
                         if (comma_ptr != NULL) {
                             snprintf(wifi_status, sizeof(wifi_status), "CONN: %s", comma_ptr + 1);
                         } else {
                             strncpy(wifi_status, "CONNECTING...", sizeof(wifi_status) - 1);
                         }
                     } else if (strcmp(status_ptr, "CONNECTED") == 0) {
                         strncpy(wifi_status, "CONNECTED", sizeof(wifi_status) - 1);
                      } else if (strcmp(status_ptr, "FAILED") == 0) {
                          strncpy(wifi_status, "CONN FAILED", sizeof(wifi_status) - 1);
                      }
                      dynamic_refresh_needed = 1;
                  } else if (strncmp(local_cmd_buf, "MOTOR:", 6) == 0) {
                      int left = 0, right = 0;
                      if (sscanf(local_cmd_buf, "MOTOR:%d,%d", &left, &right) == 2) {
                          manual_left_speed = left;
                          manual_right_speed = right;
                          last_manual_command_time = HAL_GetTick();
                          printf("[DEBUG] MOTOR RX - Left: %d, Right: %d\r\n", left, right);
                      }
                  }
             }

             // 1. Read the Bumper (HC-SR04) every 100ms instead of every loop cycle to prevent CPU blocking
             static uint32_t last_bumper_time = 0;
             static int distance = 0;
             if (current_time - last_bumper_time >= 100) {
                 last_bumper_time = current_time;
                 distance = HCSR04_Read();
             }

            // 2. Evaluate Emotion State Machine / Motor Control
            if (current_time - last_manual_command_time < 800) {
                // Manual override from webpage is active
                set_motors(manual_left_speed, manual_right_speed);
                current_emotion = EMOTION_HAPPY;
            } else {
                // Autonomous mode
                if (current_time - last_bop_time < 3000) {
                    current_emotion = EMOTION_DIZZY;
                    set_motors(0, 0); 
                } else if (distance > 0 && distance < 15) {
                    current_emotion = EMOTION_ANGRY;
                    set_motors(0, 0); 
                } else if (current_time - last_face_time > 10000) {
                    current_emotion = EMOTION_SEARCHING;
                    set_motors(0, 0); 
                } else {
                    current_emotion = EMOTION_HAPPY;
                    track_face(); 
                }
            }

            // 3. Trigger Screen Refresh on Emotion Change
            if (display_mode == 1 && last_rendered_emotion != current_emotion) {
                last_rendered_emotion = current_emotion;
                dynamic_refresh_needed = 1;
            }
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

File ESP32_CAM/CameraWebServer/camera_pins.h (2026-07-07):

#if defined(CAMERA_MODEL_WROVER_KIT)
#define PWDN_GPIO_NUM    -1
#define RESET_GPIO_NUM   -1
#define XCLK_GPIO_NUM    21
#define SIOD_GPIO_NUM    26
#define SIOC_GPIO_NUM    27

#define Y9_GPIO_NUM      35
#define Y8_GPIO_NUM      34
#define Y7_GPIO_NUM      39
#define Y6_GPIO_NUM      36
#define Y5_GPIO_NUM      19
#define Y4_GPIO_NUM      18
#define Y3_GPIO_NUM       5
#define Y2_GPIO_NUM       4
#define VSYNC_GPIO_NUM   25
#define HREF_GPIO_NUM    23
#define PCLK_GPIO_NUM    22

#elif defined(CAMERA_MODEL_ESP_EYE)
#define PWDN_GPIO_NUM    -1
#define RESET_GPIO_NUM   -1
#define XCLK_GPIO_NUM    4
#define SIOD_GPIO_NUM    18
#define SIOC_GPIO_NUM    23

#define Y9_GPIO_NUM      36
#define Y8_GPIO_NUM      37
#define Y7_GPIO_NUM      38
#define Y6_GPIO_NUM      39
#define Y5_GPIO_NUM      35
#define Y4_GPIO_NUM      14
#define Y3_GPIO_NUM      13
#define Y2_GPIO_NUM      34
#define VSYNC_GPIO_NUM   5
#define HREF_GPIO_NUM    27
#define PCLK_GPIO_NUM    25

#define LED_GPIO_NUM     4

#elif defined(CAMERA_MODEL_M5STACK_PSRAM)
#define PWDN_GPIO_NUM     -1
#define RESET_GPIO_NUM    15
#define XCLK_GPIO_NUM     27
#define SIOD_GPIO_NUM     25
#define SIOC_GPIO_NUM     23

#define Y9_GPIO_NUM       19
#define Y8_GPIO_NUM       36
#define Y7_GPIO_NUM       18
#define Y6_GPIO_NUM       39
#define Y5_GPIO_NUM        5
#define Y4_GPIO_NUM       34
#define Y3_GPIO_NUM       35
#define Y2_GPIO_NUM       32
#define VSYNC_GPIO_NUM    22
#define HREF_GPIO_NUM     26
#define PCLK_GPIO_NUM     21

#elif defined(CAMERA_MODEL_M5STACK_V2_PSRAM)
#define PWDN_GPIO_NUM     -1
#define RESET_GPIO_NUM    15
#define XCLK_GPIO_NUM     27
#define SIOD_GPIO_NUM     22
#define SIOC_GPIO_NUM     23

#define Y9_GPIO_NUM       19
#define Y8_GPIO_NUM       36
#define Y7_GPIO_NUM       18
#define Y6_GPIO_NUM       39
#define Y5_GPIO_NUM        5
#define Y4_GPIO_NUM       34
#define Y3_GPIO_NUM       35
#define Y2_GPIO_NUM       32
#define VSYNC_GPIO_NUM    25
#define HREF_GPIO_NUM     26
#define PCLK_GPIO_NUM     21

#elif defined(CAMERA_MODEL_M5STACK_WIDE)
#define PWDN_GPIO_NUM     -1
#define RESET_GPIO_NUM    15
#define XCLK_GPIO_NUM     27
#define SIOD_GPIO_NUM     22
#define SIOC_GPIO_NUM     23

#define Y9_GPIO_NUM       19
#define Y8_GPIO_NUM       36
#define Y7_GPIO_NUM       18
#define Y6_GPIO_NUM       39
#define Y5_GPIO_NUM        5
#define Y4_GPIO_NUM       34
#define Y3_GPIO_NUM       35
#define Y2_GPIO_NUM       32
#define VSYNC_GPIO_NUM    25
#define HREF_GPIO_NUM     26
#define PCLK_GPIO_NUM     21

#define LED_GPIO_NUM       2

#elif defined(CAMERA_MODEL_M5STACK_ESP32CAM)
#define PWDN_GPIO_NUM     -1
#define RESET_GPIO_NUM    15
#define XCLK_GPIO_NUM     27
#define SIOD_GPIO_NUM     25
#define SIOC_GPIO_NUM     23

#define Y9_GPIO_NUM       19
#define Y8_GPIO_NUM       36
#define Y7_GPIO_NUM       18
#define Y6_GPIO_NUM       39
#define Y5_GPIO_NUM        5
#define Y4_GPIO_NUM       34
#define Y3_GPIO_NUM       35
#define Y2_GPIO_NUM       17
#define VSYNC_GPIO_NUM    22
#define HREF_GPIO_NUM     26
#define PCLK_GPIO_NUM     21

#elif defined(CAMERA_MODEL_M5STACK_UNITCAM)
#define PWDN_GPIO_NUM     -1
#define RESET_GPIO_NUM    15
#define XCLK_GPIO_NUM     27
#define SIOD_GPIO_NUM     25
#define SIOC_GPIO_NUM     23

#define Y9_GPIO_NUM       19
#define Y8_GPIO_NUM       36
#define Y7_GPIO_NUM       18
#define Y6_GPIO_NUM       39
#define Y5_GPIO_NUM        5
#define Y4_GPIO_NUM       34
#define Y3_GPIO_NUM       35
#define Y2_GPIO_NUM       32
#define VSYNC_GPIO_NUM    22
#define HREF_GPIO_NUM     26
#define PCLK_GPIO_NUM     21

#elif defined(CAMERA_MODEL_AI_THINKER)
#define PWDN_GPIO_NUM     32
#define RESET_GPIO_NUM    -1
#define XCLK_GPIO_NUM      0
#define SIOD_GPIO_NUM     26
#define SIOC_GPIO_NUM     27

#define Y9_GPIO_NUM       35
#define Y8_GPIO_NUM       34
#define Y7_GPIO_NUM       39
#define Y6_GPIO_NUM       36
#define Y5_GPIO_NUM       21
#define Y4_GPIO_NUM       19
#define Y3_GPIO_NUM       18
#define Y2_GPIO_NUM        5
#define VSYNC_GPIO_NUM    25
#define HREF_GPIO_NUM     23
#define PCLK_GPIO_NUM     22

// 4 for flash led or 33 for normal led
#define LED_GPIO_NUM       4

#elif defined(CAMERA_MODEL_TTGO_T_JOURNAL)
#define PWDN_GPIO_NUM      0
#define RESET_GPIO_NUM    15
#define XCLK_GPIO_NUM     27
#define SIOD_GPIO_NUM     25
#define SIOC_GPIO_NUM     23

#define Y9_GPIO_NUM       19
#define Y8_GPIO_NUM       36
#define Y7_GPIO_NUM       18
#define Y6_GPIO_NUM       39
#define Y5_GPIO_NUM        5
#define Y4_GPIO_NUM       34
#define Y3_GPIO_NUM       35
#define Y2_GPIO_NUM       17
#define VSYNC_GPIO_NUM    22
#define HREF_GPIO_NUM     26
#define PCLK_GPIO_NUM     21

#elif defined(CAMERA_MODEL_XIAO_ESP32S3)
#define PWDN_GPIO_NUM     -1
#define RESET_GPIO_NUM    -1
#define XCLK_GPIO_NUM     10
#define SIOD_GPIO_NUM     40
#define SIOC_GPIO_NUM     39
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

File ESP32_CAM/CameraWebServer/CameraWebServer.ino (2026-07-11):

#include "esp_camera.h"
#include <WiFi.h>
#include <WiFiClientSecure.h>
#include <PubSubClient.h>
#include "soc/soc.h"           // Disable brownout problems
#include "soc/rtc_cntl_reg.h"  // Disable brownout problems

//
// WARNING!!! PSRAM IC required for UXGA resolution and high JPEG quality
//            Ensure ESP32 Wrover Module or other board with PSRAM is selected
//            Partial images will be transmitted if image exceeds buffer size
//
//            You must select partition scheme from the board menu that has at least 3MB APP space.
//            Face Recognition is DISABLED for ESP32 and ESP32-S2, because it takes up from 15 
//            seconds to process single frame. Face Detection is ENABLED if PSRAM is enabled as well

// ===================
// Select camera model
// ===================
//#define CAMERA_MODEL_WROVER_KIT // Has PSRAM
//#define CAMERA_MODEL_ESP_EYE // Has PSRAM
//#define CAMERA_MODEL_ESP32S3_EYE // Has PSRAM
//#define CAMERA_MODEL_M5STACK_PSRAM // Has PSRAM
//#define CAMERA_MODEL_M5STACK_V2_PSRAM // M5Camera version B Has PSRAM
//#define CAMERA_MODEL_M5STACK_WIDE // Has PSRAM
//#define CAMERA_MODEL_M5STACK_ESP32CAM // No PSRAM
//#define CAMERA_MODEL_M5STACK_UNITCAM // No PSRAM
#define CAMERA_MODEL_AI_THINKER // Has PSRAM
//#define CAMERA_MODEL_TTGO_T_JOURNAL // No PSRAM
//#define CAMERA_MODEL_XIAO_ESP32S3 // Has PSRAM
// ** Espressif Internal Boards **
//#define CAMERA_MODEL_ESP32_CAM_BOARD
//#define CAMERA_MODEL_ESP32S2_CAM_BOARD
//#define CAMERA_MODEL_ESP32S3_CAM_LCD
//#define CAMERA_MODEL_DFRobot_FireBeetle2_ESP32S3 // Has PSRAM
//#define CAMERA_MODEL_DFRobot_Romeo_ESP32S3 // Has PSRAM
#include "camera_pins.h"

#include "secrets.h"
#include "FS.h"
#include "SD_MMC.h"
#include <Preferences.h>

#include "app_httpd.h"

struct WiFiCreds {
  String ssid;
  String password;
};

WiFiCreds wifiList[10];
int wifiCount = 0;
Preferences prefs;
String lastSSID = "";
String lastPassword = "";

void loadWiFiFromSD() {
  Serial.println("Initializing SD Card in 1-bit mode...");
  if (!SD_MMC.begin("/sdcard", true)) {
    Serial.println("SD Card mount failed. Using fallback credentials.");
    return;
  }

  File file = SD_MMC.open("/wifi.txt");
  if (!file) {
    Serial.println("Failed to open /wifi.txt. Using fallback credentials.");
    SD_MMC.end();
    return;
  }

  Serial.println("Parsing /wifi.txt...");
  wifiCount = 0;
  while (file.available() && wifiCount < 10) {
    String line = file.readStringUntil('\n');
    line.trim();
    if (line.length() == 0 || line.startsWith("#")) continue;
    
    int commaIdx = line.indexOf(',');
    if (commaIdx != -1) {
      String s = line.substring(0, commaIdx);
      String p = line.substring(commaIdx + 1);
      s.trim();
      p.trim();
      if (s.length() > 0) {
        wifiList[wifiCount].ssid = s;
        wifiList[wifiCount].password = p;
        wifiCount++;
      }
    }
  }
  file.close();
  SD_MMC.end();
  Serial.printf("Parsed %d WiFi credentials from SD card.\n", wifiCount);
}

void loadLastWiFi() {
  prefs.begin("wifi-store", false);
  lastSSID = prefs.getString("last-ssid", "");
  lastPassword = prefs.getString("last-pass", "");
  prefs.end();
}

void saveLastWiFi(String s, String p) {
  prefs.begin("wifi-store", false);
  prefs.putString("last-ssid", s);
  prefs.putString("last-pass", p);
  prefs.end();
}

void sendWiFiListToNucleo() {
  if (wifiCount == 0) {
    Serial.printf("WIFILIST:%s\n", ssid);
    return;
  }
  
  String msg = "WIFILIST:";
  for (int i = 0; i < wifiCount; i++) {
    msg += wifiList[i].ssid;
    if (i < wifiCount - 1) {
      msg += ",";
    }
  }
  msg += "\n";
  Serial.print(msg);
}

void connectWiFiOnBoot() {
  loadWiFiFromSD();
  loadLastWiFi();

  WiFi.persistent(false);
  WiFi.mode(WIFI_STA);
  WiFi.setTxPower(WIFI_POWER_15dBm);

  if (lastSSID.length() > 0) {
    Serial.printf("Connecting to last used WiFi: %s\n", lastSSID.c_str());
    Serial.printf("WIFISTATUS:CONNECTING,%s\n", lastSSID.c_str());
    WiFi.begin(lastSSID.c_str(), lastPassword.c_str());
    
    int retries = 20;
    while (WiFi.status() != WL_CONNECTED && retries > 0) {
      delay(500);
      Serial.print(".");
      retries--;
    }
    
    if (WiFi.status() == WL_CONNECTED) {
      Serial.println("\nWiFi connected to last used!");
      Serial.println("WIFISTATUS:CONNECTED");
      return;
    }
    Serial.println("\nFailed to connect to last used WiFi.");
  }

  for (int i = 0; i < wifiCount; i++) {
    if (wifiList[i].ssid == lastSSID) continue;
    
    Serial.printf("Trying SD WiFi: %s\n", wifiList[i].ssid.c_str());
    Serial.printf("WIFISTATUS:CONNECTING,%s\n", wifiList[i].ssid.c_str());
    WiFi.begin(wifiList[i].ssid.c_str(), wifiList[i].password.c_str());
    
    int retries = 20;
    while (WiFi.status() != WL_CONNECTED && retries > 0) {
      delay(500);
      Serial.print(".");
      retries--;
    }
    
    if (WiFi.status() == WL_CONNECTED) {
      Serial.println("\nWiFi connected to SD list entry!");
      Serial.println("WIFISTATUS:CONNECTED");
      saveLastWiFi(wifiList[i].ssid, wifiList[i].password);
      return;
    }
    Serial.println("\nFailed.");
  }

  Serial.printf("Trying compiled fallback WiFi: %s\n", ssid);
  Serial.printf("WIFISTATUS:CONNECTING,%s\n", ssid);
  WiFi.begin(ssid, password);
  int retries = 20;
  while (WiFi.status() != WL_CONNECTED && retries > 0) {
    delay(500);
    Serial.print(".");
    retries--;
  }
  
  if (WiFi.status() == WL_CONNECTED) {
    Serial.println("\nWiFi connected to compiled fallback!");
    Serial.println("WIFISTATUS:CONNECTED");
    saveLastWiFi(ssid, password);
  } else {
    Serial.println("\nAll WiFi connections failed.");
    Serial.println("WIFISTATUS:FAILED");
  }
}

void connectToSelectedWiFi(int idx) {
  if (idx < 0 || idx >= wifiCount) {
    Serial.println("Invalid WiFi index selected.");
    Serial.println("WIFISTATUS:FAILED");
    return;
  }
  
  String selected_ssid = wifiList[idx].ssid;
  String selected_pass = wifiList[idx].password;
  
  Serial.printf("Connecting to requested WiFi: %s\n", selected_ssid.c_str());
  Serial.printf("WIFISTATUS:CONNECTING,%s\n", selected_ssid.c_str());
  
  WiFi.disconnect();
  WiFi.begin(selected_ssid.c_str(), selected_pass.c_str());
  
  int retries = 20;
  while (WiFi.status() != WL_CONNECTED && retries > 0) {
    delay(500);
    Serial.print(".");
    retries--;
  }
  
  if (WiFi.status() == WL_CONNECTED) {
    Serial.println("\nWiFi connected to selected!");
    Serial.println("WIFISTATUS:CONNECTED");
    saveLastWiFi(selected_ssid, selected_pass);
  } else {
    Serial.println("\nFailed to connect to selected WiFi.");
    Serial.println("WIFISTATUS:FAILED");
  }
}

WiFiClientSecure net;
PubSubClient mqttClient(net);
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

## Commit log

2026-07-07 Initial commit: DesktopBuddy core architecture and emotion engine
    Brought DesktopBuddy to life with a dual-microcontroller architecture (ESP32-CAM + STM32 Nucleo-F411RE).
    This initial release includes the complete hardware stack, sensory inputs, and the Emotion Engine.
    Key Features Included:
    - The Brain (ESP32): Integrated neural network face-detection streaming coordinate data via AWS IoT and local UART.
    - The Legs (Nucleo): Wrote a custom Proportional-Integral (PI) tracking loop to drive the L298N motors and dynamically center on faces.
    - The Senses: Fully integrated the SGP30 (Air Quality) over I2C and a microsecond-accurate HC-SR04 sonar driver for collision avoidance.
    - The Personality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
    [partitions.csv]
2026-07-07 Update README and add documentation for AWS IoT setup, system architecture, and wiring guide
2026-07-07 Optimize ESP32 thread-safety, remap Nucleo TX to D10, bypass VBUS conflict, and secure certificates/secrets
2026-07-07 Remove diagnostic TX: OK OLED print
2026-07-07 Update system architecture diagram and wiring guide with PB6/D10 remap
2026-07-07 Set default screen to face and implement smart status-based LED patterns
2026-07-07 Revert ESP32 LED changes and implement emotion-based user LED patterns on Nucleo PA5
    [CameraWebServer.ino, main.c]
2026-07-07 Implement peak-hold logic for air quality sensor: poll every 1s, transmit max every 5s
2026-07-08 Revert interactive menu and handshake link check while maintaining background Wi-Fi status reporting on OLED with line padding and include string.h and strip trailing crlf
    [main.c]
2026-07-08 Fix camera resolution fallback to QVGA for non-PSRAM environments to allow face detection
    [CameraWebServer.ino]
2026-07-08 Add volatile qualifier to global tracking variables updated in UART ISR to prevent optimization caching
    [main.c]
2026-07-10 Scale motor compare speed values to TIM3 period (65535) in set_motors
2026-07-10 Add startup motor wiggle test to confirm operation at boot
2026-07-10 Add new 3D design files for robot components
    [Base.FCStd, Unnamed.FCStd]
2026-07-10 Add KiCad ECAD files and 3D models with proper gitignore rules
    [.kicad_sch, DM-OLED096-636--3DModel-STEP-56544.STEP, DM-OLED096-636.step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]
2026-07-10 Remove obsolete 3d_Design files
    [Base.FCStd, Unnamed.FCStd]
2026-07-11 Add physical button control on GPIO13 to cycle ESP32-CAM LED flash intensity
2026-07-11 Update KiCad schematic and layout with new ESP32 button circuitry
    [nucleo_shield_pcb.kicad_pcb, nucleo_shield_pcb.kicad_sch]
2026-07-11 Reposition button pinMode to end of setup() to prevent SD unmounting overwrite
    [CameraWebServer.ino]
2026-07-11 Change button input pin from GPIO13 to GPIO12
2026-07-11 Revert button pin back to GPIO13
    [CameraWebServer.ino]
2026-07-11 Copy core webserver source files to the sketch folder to resolve compilation errors
    [app_httpd.cpp, camera_pins.h]
2026-07-11 Remove redundant source files from parent ESP32_CAM directory
2026-07-11 Extract and save original readable HTML interface from camera_index.h
2026-07-11 Enhance ESP32_CAM Web Interface and Nucleo_F411RE Motor Control
    - Updated camera_index.html to improve UI with new styles, fonts, and telemetry display for Wi-Fi status, CO2 levels, TVOC, and distance.
    - Added motor control buttons with keyboard support for manual operation of motors.
    - Implemented telemetry updates via periodic polling for real-time data display.
    - Modified main.c to handle manual motor control commands received from the web interface, allowing for manual override of autonomous behavior.
    - Enhanced emotion state machine logic to prioritize manual commands over autonomous actions.
2026-07-11 Enhance motor control responsiveness and implement soft start feature
    - Reduced motor command execution delay in ESP32 camera web server for quicker response.
    - Adjusted backup stop command timing for improved reliability.
    - Introduced motor acceleration ramping in Nucleo firmware to prevent current surges.
    - Implemented button press handling for menu options on the OLED display.
    - Increased I2C clock speed for better communication efficiency.
    [CameraWebServer.ino, app_httpd.cpp, main.c]
2026-07-11 Fix component footprint libraries and resolve button shield pin mapping errors
    [nucleo_shield_pcb.kicad_pcb, nucleo_shield_pcb.kicad_sch]
2026-07-11 Update PCB and schematic: wire sensors, motor driver connector, and buttons
    [nucleo_shield_pcb.kicad_pcb, nucleo_shield_pcb.kicad_sch]
2026-07-11 Add Mimir logo to PCB and update layout
    [nucleo_shield_pcb.kicad_pcb]
2026-07-11 Configure 2.0mm JST PH connector for SGP30 sensor and generate Gerbers
    [nucleo_shield_pcb-B_Cu.gbr, nucleo_shield_pcb-B_Mask.gbr, nucleo_shield_pcb-B_Paste.gbr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]
2026-07-11 Clean up redundant project files and duplicate 3D models
    [.kicad_sch, DM-OLED096-636--3DModel-STEP-56544.STEP, SEN-09836--3DModel-STEP-510211.STEP]
2026-07-11 Add 3D STEP model of the PCB for Fusion 360 integration
    [pcb.step]
2026-07-13 Added 3d Model for F411RE Nucleo board
2026-07-18 Updated Schematic, removed TODO
    [nucleo_shield_pcb.kicad_sch]
